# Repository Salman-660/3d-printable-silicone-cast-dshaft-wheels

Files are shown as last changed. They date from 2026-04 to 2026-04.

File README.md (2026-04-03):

# 3d Printable High-Traction Silicone Wheels: (re-engineered for D-Shaft)

This project provides a comprehensive, open-source hardware solution for manufacturing high-grip robot wheels using Platinum Cure Silicone. While inspired by the original DrumBotics design, this iteration has been fundamentally re-engineered to support the needs of builders who may not have the luxury of pausing 3D prints to insert hardware or the ability to source specific tiny nuts and bolts. 

By utilizing a precision-engineered direct-fit D-bore, these wheels mount securely to N20 micro-gear motors without the need for any external set-screws or bolt tightening. This makes the design ideal for those who choose to outsource their 3D prints, as the final product requires no mid-print manual intervention. Both **STL files** (for immediate printing) and **STEP files** (for easy editing and customization) are included for the mold and the rim.

---

###  Design Philosophy and Technical Specs
The core of this design focuses on mechanical reliability and weight optimization. The wheel rim features a specialized 8-spoke "T-hook" geometry which creates a permanent mechanical bond with the silicone tire, ensuring the tread cannot slip off during high-torque maneuvers. To maintain a low weight for agile robots like line-followers and large-size micromice, the rim includes cylindrical cut-outs. The mold itself is a lid-free, dual-cavity design crafted to minimize material usage and print time.

| Component | Dimensions / Stats | Notes |
| :--- | :--- | :--- |
| **Total Wheel Diameter** | 42 mm | Includes 1 mm internal traction grooves |
| **Wheel Thickness** | 20 mm | Optimized for maximum surface contact |
| **Rim Radius** | 13.67 mm | 8-spoke "T-hook" mechanical anchors |
| **Shaft Interface** | 3 mm D-Bore | Direct-fit design; no screws or bolts |
| **D-Bore Tolerance** | ± 0.3 mm | Refined for a press-fit, slip-resistant finish |
| **Predicted Rim Mass** | ~9.12 g | Calculated for PLA at 100% infill |
| **Predicted Mold Mass** | ~92.6 g | Calculated at 100% infill for reference |
| **Mold Dimensions** | 105 x 56 x 26.5 mm | Material-efficient, lid-free construction |

---

###  Fabrication & Material Guidelines

**3D Printing Strategy**
* **Rims:** Should be printed at **maximum infill** (100%) to ensure the D-bore remains rigid and resistant to wear over time. 
* **Molds:** Designed to be material-efficient; printing at a **low infill (approximately 20%)** provides sufficient strength while reducing filament consumption. 
* **Tested Material:** The primary documentation and tolerances are based on **PLA** for both the rim and mold.

**Tolerance Testing**
Because every 3D printer and material handles tolerances differently, a dedicated `D_Bore_Test.stl` is provided. This is especially critical for anyone who chooses to use materials other than PLA, as different plastics may change the tolerance and cause a misfit. It is highly recommended to print this small test piece first to verify your motor shaft fit before committing to a full print. 

**Silicone Selection and Handling**
This design was validated using [Bluebird Platinum Silicone](https://bluebirdarts.pk/products/bluebird-platinum-silicone-liquid-rubber-set-of-1-kg-epoxy-mold-making), which is a bubble-free mixture ideal for high-quality DIY molding without a vacuum chamber.
* **Mixing Ratio:** 1A : 1B by weight.
* **Color:** Translucent (A), Translucent (B), and Translucent after curing.
* **Volume:** Approximately 17 ml of silicone mixture is used per wheel (measured by syringe).

**Casting Tips**
* **Release Agent:** You can use mold release wax or petroleum jelly (Vaseline) spread perfectly without leaving any bulged residue.
* **Syringe Discipline:** Keep track of which syringe you use for each liquid (A or B). A mistaken swap can cure the silicone inside the syringe or the bottle, ruining your entire kit.

> [!IMPORTANT]
> **Thermal Curing Warning:** If you are printing your mold in **PLA**, you must avoid thermal curing. PLA has a low glass transition temperature (~60°C). Attempting to cure silicone at high heat (such as 100°C) will warp the mold and ruin your precision tolerances.

---

###  Assembly and Casting Process

To achieve perfect concentricity and avoid misplacement or off-centering, do not use 3D-printed alignment shafts, as they will be rough and create complexity. Instead, utilize the actual steel D-shafts from an old N20 motor. 

1. **Shaft Extraction:** Open the gearbox of an old N20 motor with screws and tear it down using pliers to remove the D-shaft.
2. **Mold Setup:** Insert these steel shafts through the bottom of the mold cavity from beneath to center-align the wheel rims before pouring the silicone. 
3. **Symmetry:** This setup ensures the wheel remains perfectly centered and symmetrical during the curing process.

---

###  Design Reference

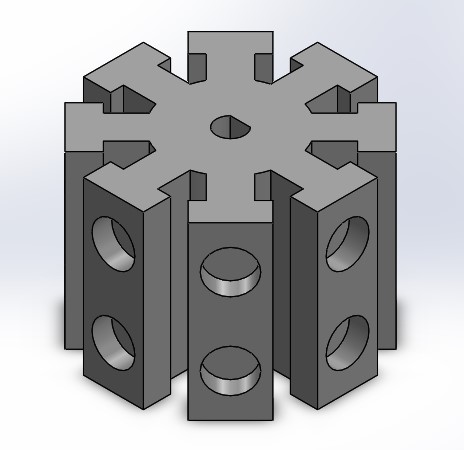
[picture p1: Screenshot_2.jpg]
Hub Geometry - 8 Spoke Design

*Figure 1: Isometric view of the 8-spoke "T-hook" anchors and weight-reduction cuts.*

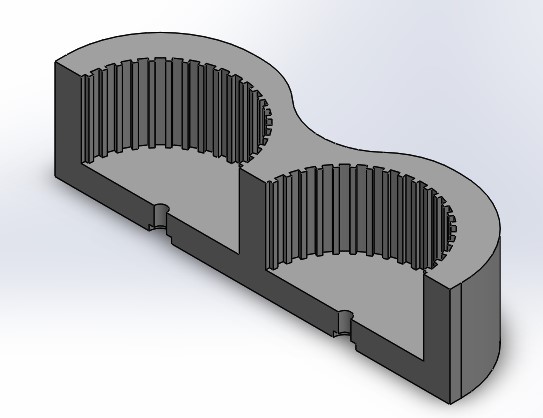
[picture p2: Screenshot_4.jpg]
Mold Cavity Section

*Figure 2: Section view of the dual-cavity mold showing the integrated traction teeth.*

---

### ⚖️ Attribution & Support
Original inspiration by **DrumBotics**. This project provides a hardware-free alternative for the robotics community, specifically targeted at those who need a reliable D-shaft fit without complex assembly.

**Original Inspiration:** [DrumBotics - Silicone Wheels Tutorial](https://youtu.be/wSwuph2TElI?si=L_Lbu_0M20XGUKMt)

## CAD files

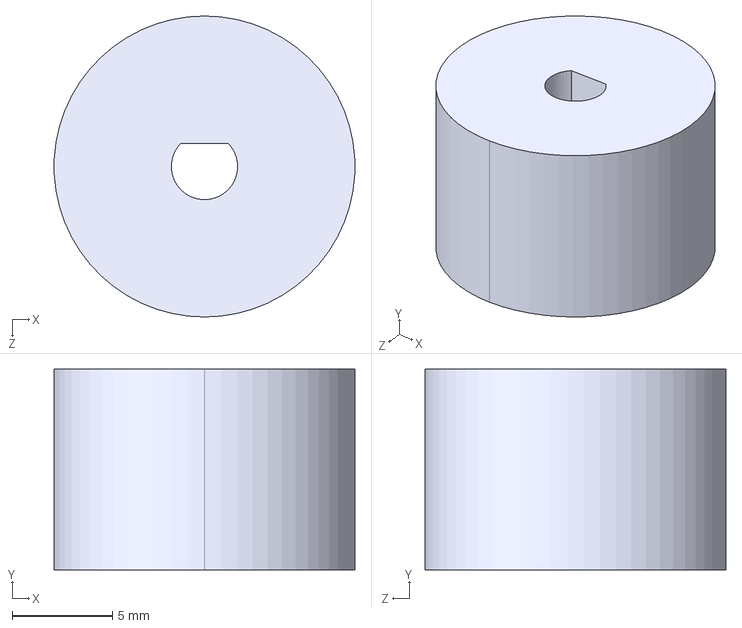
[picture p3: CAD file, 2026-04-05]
D_Bore_Test.STEP
15.0 x 10.0 x 15.0 mm

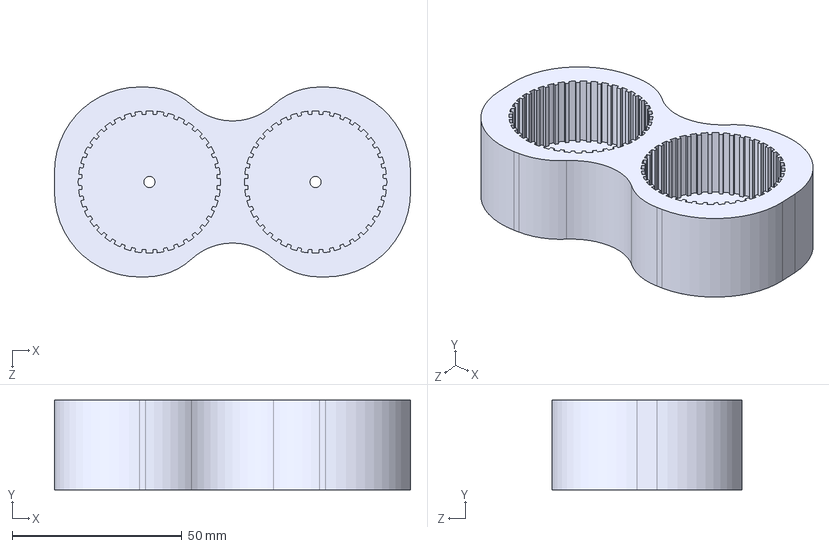
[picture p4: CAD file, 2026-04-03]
mold_v1.STEP
105.0 x 26.5 x 56.0 mm

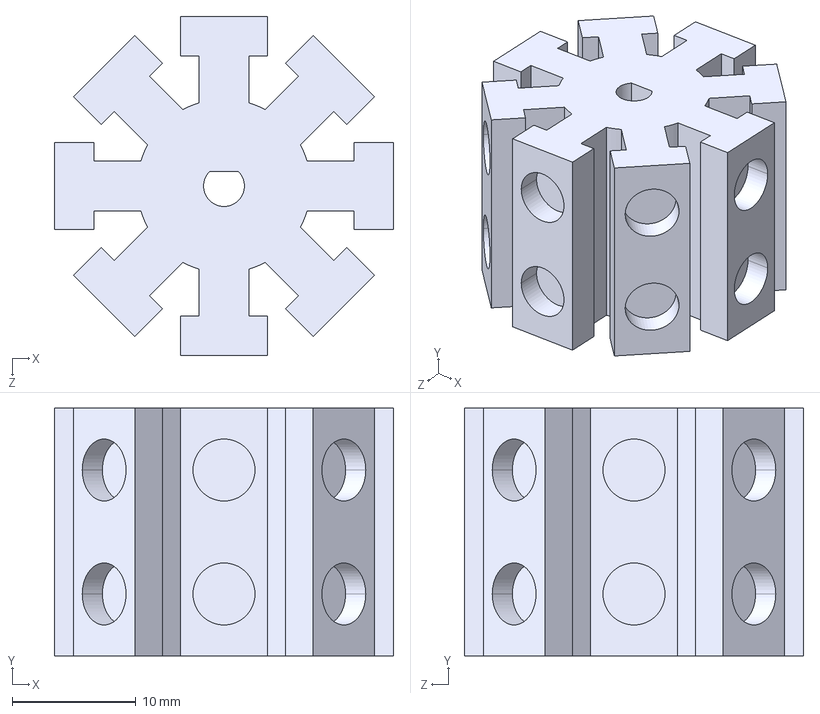
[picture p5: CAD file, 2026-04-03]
rim_v1.STEP
27.3 x 20.0 x 27.3 mm

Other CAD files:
D_Bore_Test.STL
mold_v1.STL
rim_v1.STL

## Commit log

2026-04-03 Add CAD files.
    [mold_v1.STEP, mold_v1.STL, rim_v1.STEP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]
2026-04-05 Add D-bore test files. Closes #1
    [D_Bore_Test.STEP, D_Bore_Test.STL]
